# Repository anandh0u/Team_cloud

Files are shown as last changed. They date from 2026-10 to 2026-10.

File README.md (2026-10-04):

<div align="center">

# 🛏️🤖 Bedside Assistant

**A voice-controlled robotic arm and caregiver link for people who can't easily move.**









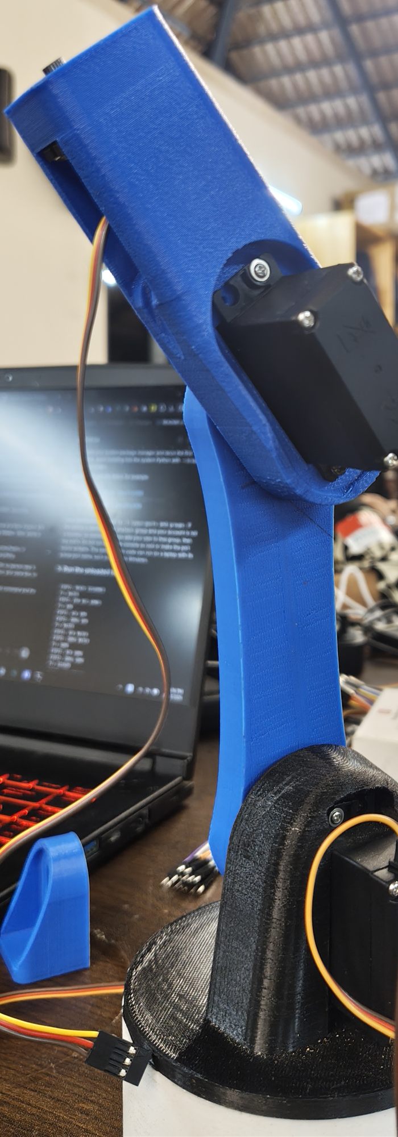
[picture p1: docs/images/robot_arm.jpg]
The 3D-printed robotic arm with MG996R servos

&nbsp;&nbsp;
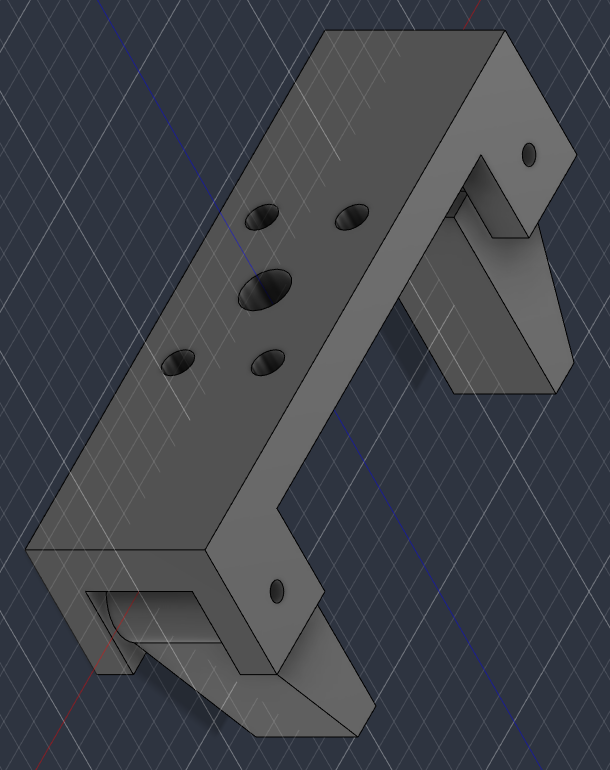
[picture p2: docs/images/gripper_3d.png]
3D model of the two-jaw gripper


</div>

---

## 💡 The problem

For someone who is bedridden, partly paralysed or in a wheelchair, everyday things are out of
reach: a glass of water, their medicine, their phone, a spoon. Asking for each one makes them
dependent on someone always being in the room, and a caregiver who steps out has no idea how
the patient is doing.

**The Bedside Assistant sits next to the bed.** The patient just speaks, in English or their own
Indian language, and a small robotic arm fetches what they need. A camera checks the object is
really there, the assistant answers out loud, and the caregiver gets a live dashboard, daily
activity reports and an immediate phone call if the patient says "help".

> ⚠️ **Hackathon prototype. Not a medical device:** it never diagnoses anything, and its pulse
> reading comes from a hobby sensor.

---

## ✨ What it does

| | |
|---|---|
| 🗣️ **Talk naturally** | "I want spoon", "can you get me something to drink", "where is my phone?" in English, Malayalam, Hindi, Tamil and other Indian languages. Replies are spoken back in the same language. |
| 🦾 **Fetch objects** | The arm opens its gripper, goes to the object's spot, grips it and holds it out to the patient. "Let go" releases it. |
| 👁️ **See the table** | A phone camera on a bedside stand runs live object detection. The arm only moves for an object the camera actually sees, and "where is my phone?" gets "on the left, next to the laptop". |
| 🚨 **Help in one word** | "Help", "I fell" or "call Ayisha" stops the arm instantly and phones the caregiver, hands-free. |
| 📊 **Caregiver dashboard** | Live camera picture, whether the patient is lying or sitting up, when they last moved, pulse, and every request and alert. Works from anywhere, behind a password. |
| 📈 **Activity reports** | Compares today with yesterday ("moved in 42% of checks, up from 30%") with a 7-day chart and a plain-language AI summary for the family. |

---

## 🧭 How it works

```mermaid
flowchart LR
    subgraph BED["🛏️ At the bedside"]
        P(["🧑‍🦽 Patient"])
        PH["📱 Bedside phone<br/>mic · camera · speaker<br/>/phone page"]
        ARM["🦾 Robotic arm<br/>base · shoulder · elbow · gripper"]
        SEN["💓 Pulse sensor<br/>📐 MPU6050"]
    end

    subgraph PI["🍓 Raspberry Pi 5: the brain"]
        INT["🧠 Intent rules<br/>+ AI fallback"]
        VIS["👁️ YOLO11<br/>objects + pose"]
        SAFE["🛡️ Safety checks"]
        DASH["📊 Dashboard · 📈 Reports<br/>🗄️ SQLite history"]
    end

    ESP["⚙️ ESP32<br/>controller"]

    subgraph CLOUD["☁️ Cloud services"]
        SAR["🗣️ Sarvam AI<br/>speech ⇄ text, translation"]
        OAI["🤖 OpenAI<br/>text + numbers only"]
    end

    subgraph CARE["👩‍⚕️ Caregiver"]
        CG["💻 Dashboard anywhere<br/>(password, HTTPS tunnel)"]
        CALL["📞 Call via MacroDroid"]
        SMS["✉️ SMS gateway phone"]
    end

    P -- speaks --> PH
    PH -- "voice + live frames" --> PI
    PI -- "spoken reply" --> PH
    PI <--> SAR
    PI <--> OAI
    PI -- "named poses only<br/>(SPOON, USER…)" --> ESP
    ESP --> ARM
    SEN --> ESP
    ESP -- telemetry --> PI
    PI --> CG
    PI --> CALL
    PI --> SMS
```

- The **phone** replaces a separate camera, microphone and speaker: it just opens a web page served by the Pi.
- The **Raspberry Pi** does all the thinking. It runs vision on its own CPU, so **camera pictures never leave the Pi**.
- The **ESP32** owns the motors. The Pi only asks for named poses (`SPOON`, `USER`, …), and the ESP32 checks them against each joint's safe limits, so no bug or bad request upstream can drive a servo into the bed.

### 🎙️ One request, end to end: *"I want my spoon"*

```mermaid
sequenceDiagram
    autonumber
    actor P as 🧑‍🦽 Patient
    participant PH as 📱 Phone
    participant PI as 🍓 Raspberry Pi
    participant S as 🗣️ Sarvam AI
    participant Y as 👁️ YOLO11 (on the Pi)
    participant E as ⚙️ ESP32 + 🦾 arm

    P->>PH: "I want my spoon"
    PH->>PI: voice clip + live camera frames
    PI->>S: speech → text (translated to English if needed)
    S-->>PI: "I want my spoon"
    Note over PI: Intent rules → GET_OBJECT spoon<br/>(AI only if no rule matches)
    PI->>Y: seen in the last 10 s?
    Y-->>PI: ✅ spoon, on the left
    PI->>E: gripper open → pose SPOON → gripper close → pose USER
    E-->>PI: ✅ done (each step waits until the arm is still)
    PI->>S: reply text → speech (patient's language)
    S-->>PI: audio
    PI-->>PH: 🔊 "I found your spoon on the left and brought it to you."
    P->>PH: "Let go"
    PI->>E: gripper open
```

### 🛡️ When does the arm actually move?

Every fetch must pass **all** of these checks. Fail any one and the arm stays still and the patient
is told why.

```mermaid
flowchart TD
    A(["🗣️ Request"]) --> B{"🚨 Emergency or STOP<br/>phrase?"}
    B -- yes --> X["🛑 Handled instantly by fixed rules<br/>(see emergency flow)"]
    B -- no --> C{"Matched by the<br/>fixed rules?"}
    C -- no --> D["🤖 AI picks a REAL action,<br/>object and contact only"]
    C -- yes --> E
    D --> E{"Can the camera<br/>recognise this object?"}
    E -- "yes (spoon, phone, cup…)" --> F{"👁️ Seen in a frame<br/>from the last 10 s?"}
    E -- "no (medicine)" --> G
    F -- no --> N1["🙅 'I can't see your spoon on the table,<br/>so I didn't move the arm.'"]
    F -- yes --> G{"📏 Pose calibrated<br/>on the ESP32?"}
    G -- no --> N2["🙅 Refused: uncalibrated pose"]
    G -- yes --> H{"⚙️ ESP32: within joint limits<br/>and not STOPPED?"}
    H -- no --> N3["🙅 Refused by the ESP32"]
    H -- yes --> M(["🦾 Arm moves"])
```

### 🚨 Emergency flow

```mermaid
flowchart LR
    H(["'Help!' / 'I fell' /<br/>'call Ayisha'"]) --> R["⚡ Matched instantly on the Pi<br/>(no internet, no AI)"]
    R --> S1["🛑 STOP the arm"]
    R --> S2["📞 Call caregiver<br/>(MacroDroid)"]
    R --> S3["✉️ SMS caregiver<br/>(if a gateway is set up)"]
    S1 & S2 & S3 --> OUT{"Did the alert<br/>get through?"}
    OUT -- yes --> Y1["🔊 'I am contacting your caregiver.'"]
    OUT -- no --> Y2["🔊 'I could not reach your caregiver.<br/>Please call out for help.'"]
```

The stop and the alert run **in parallel**, so an unreachable ESP32 can never delay the call.
After a STOP the arm refuses every motion until someone explicitly resumes it.

---

## 📁 Repository

| Folder | What |
|---|---|
| 🍓 [`raspberry_pi/`](raspberry_pi/) | The brain: Python/FastAPI server, phone page, dashboard, reports. [Setup and details →](raspberry_pi/README.md) |
| ⚙️ [`esp32_controller/`](esp32_controller/) | Arm and sensor firmware (Arduino), with a browser calibration page. [Wiring and details →](esp32_controller/README.md) |
| 🦾 [`gripper_cad/`](gripper_cad/) | 3D-printable two-jaw gripper: ready STL/STEP files and the parametric Fusion 360 script |
| 🖼️ [`docs/images/`](docs/images/) | Photos and renders used in this README |

---

## 🔧 Hardware

| Part | Notes |
|---|---|
| 🍓 Raspberry Pi 5 (4 GB+) | Runs everything on the CPU, no accelerator needed |
| ⚙️ ESP32 Dev Module | Arm and sensor controller (Wi-Fi is **2.4 GHz only**) |
| 🦾 3-joint arm + gripper, 4 hobby servos | e.g. MG996R joints, SG90 gripper; separate 5–6 V, ≥3 A supply |
| 🖨️ 3D-printed gripper | [`gripper_cad/export/`](gripper_cad/export/) |
| 📱 Android phone on a bedside stand | Camera, microphone, speaker; MacroDroid for hands-free calls |
| 💓 MPU6050, analog pulse sensor | Optional, for the dashboard |

### 🔌 Wiring

```mermaid
flowchart LR
    subgraph PWR["🔋 Servo supply 5–6 V"]
        VP["+"]
        VN["−"]
    end
    subgraph ESP["⚙️ ESP32"]
        G13["GPIO 13"]
        G14["GPIO 14"]
        G27["GPIO 27"]
        G26["GPIO 26"]
        G21["GPIO 21 SDA"]
        G22["GPIO 22 SCL"]
        G34["GPIO 34"]
        V33["3V3"]
        GND["GND"]
    end
    G13 --> BASE["Base servo"]
    G14 --> SH["Shoulder servo"]
    G27 --> EL["Elbow servo"]
    G26 --> GR["Gripper servo"]
    G21 --- MPU["📐 MPU6050"]
    G22 --- MPU
    G34 --- PUL["💓 Pulse sensor"]
    V33 --> MPU
    V33 --> PUL
    VP --> BASE & SH & EL & GR
    VN --- GND
```

| Part | ESP32 pin |
|---|---|
| Base / shoulder / elbow servo signal | **GPIO 13 / 14 / 27** |
| Gripper servo signal | **GPIO 26** |
| Servo red (+) / brown (−) | **external 5–6 V supply**, never the ESP32 |
| MPU6050 VCC / GND / SDA / SCL | **3V3** / GND / **GPIO 21** / **GPIO 22** |
| Pulse sensor + / − / S | **3V3** (not 5 V) / GND / **GPIO 34** |
| Optional STOP button | any free pin to GND (`STOP_BUTTON_PIN`) |

> 🔌 **Join all grounds:** servo supply −, every servo's brown wire, the sensor GNDs and the ESP32 GND.
> Without a common ground the servos won't move.
>
> ⚡ **Never power servos from the ESP32's VIN / 5V / 3V3.** Their current spikes reset the board and can
> stop it reading its own flash.

---

## 🚀 Quick start

1. 🍓 **Raspberry Pi:** follow [raspberry_pi/README.md](raspberry_pi/README.md#setup). With
   `MOCK_HARDWARE=true` the whole system runs with a simulated arm, so you can try it without any hardware.
2. ⚙️ **ESP32:** wire it and upload the firmware as in [esp32_controller/README.md](esp32_controller/README.md),
   then calibrate the poses in a browser at `http://<ESP32 IP>/calibrate` and put the ESP32's
   IP in the Pi's `.env`.
3. 📱 **Phone:** open `https://<Pi IP>:8443/phone`, allow camera and microphone, point it at the table.
4. 👩‍⚕️ **Caregiver:** open `http://<Pi IP>:8000/dashboard`, or `scripts/start.sh --online` for a link that works anywhere.

---

## 🎬 Demo

| Say | What happens |
|---|---|
| 👁️ "Where is my spoon?" | "I can see your spoon on the left, next to the laptop." |
| 🦾 "I want spoon" | The arm opens, goes to the spoon, grips it and holds it out: "I found your spoon on the left and brought it to you." |
| ✋ "Let go" | The gripper releases the spoon |
| 🌏 (in Malayalam) "എന്റെ ഫോൺ എവിടെ?" | Understood as "Where is my phone?" and answered in Malayalam |
| 🙅 "Bring me my phone" when it isn't on the table | "I can't see your phone on the table, so I didn't move the arm." |
| 🚨 "Help" | The arm freezes and the bedside phone calls the caregiver on speaker |
| 📈 Caregiver opens `/report` | "More active: moved in 43% of checks, compared with 30% the day before" plus an AI summary |

---

## 🛡️ Safety and privacy

- 🚨 **Emergency and STOP are matched instantly on the Pi**, with fixed replies. They never wait
  for the internet or the AI, and an emergency stops the arm and alerts the caregiver in parallel.
- 🦾 **The arm only moves for a reason:** the object must be visible in a recent camera frame, its
  pose must be calibrated, and the ESP32 enforces joint limits and refuses all motion after a STOP.
  Every step waits for the arm to be still, so a STOP is never queued behind a move.
- 🤖 **The AI is boxed in.** It only sees sentences the rules can't match, can only choose real
  actions, objects and contacts, and rewrites replies from what actually happened. If it fails,
  the fixed rules and replies take over.
- 🔒 **Privacy:** camera pictures stay on the Pi; the history stores numbers only; OpenAI receives
  text and numbers, never images. Every page sits behind a password.
- 🩺 **No diagnoses:** reports describe activity ("more active than yesterday") and never say a
  patient is improving or getting worse. Changes are flagged for the doctor or nurse.

---

## 🧰 Built with

Python · FastAPI · Ultralytics YOLO11 (detection + pose) · Sarvam AI (speech-to-text,
translation, text-to-speech for Indian languages) · OpenAI (`gpt-5.4-mini`) · SQLite ·
ESP32 / Arduino · MacroDroid · Cloudflare Tunnel · Fusion 360

✅ 248 automated tests on the Pi software, with no hardware or internet needed: `python -m pytest -q`

---

## 📌 Status and limitations

- ✅ **Working end to end on real hardware:** voice in English and Malayalam (spoken reply in
  Malayalam), live detection, camera-checked fetching with the arm, dashboard and reports.
- 📞 **Calls:** the Pi reaches MacroDroid on the bedside phone, which places the call; a full
  "help" call to the caregiver still needs a final check on the day.
- ⏱️ **Response time:** about 3–5 s in English; up to about 10 s for other languages, because
  speech recognition, the AI reply, translation and speech are each a network call. Emergency
  and STOP don't wait for the AI.
- 📍 **Fixed object spots:** the arm goes to calibrated positions, so each object has its place on
  the table. It doesn't plan a path to wherever the object is.
- 💊 **Medicine isn't recognised** by the general-purpose YOLO model. It's fetched from its spot
  without a camera check; a custom-trained model would fix that.
- 🥄 **Spoons and other small, shiny objects** are detected less reliably than bottles or phones.
  A steady camera and a plain background help.
- 📐 **Our MPU6050 is a clone** (chip ID 0x70) whose accelerometer returns zeros, so the dashboard
  shows motion as unavailable. A genuine MPU6050 works without code changes.
- ✉️ **SMS** needs an Android gateway phone; without one, messages are only logged. Calls work through MacroDroid.

---

## 🩹 Troubleshooting

| Problem | Fix |
|---|---|
| 📶 ESP32 can't find the Wi-Fi | It's 2.4 GHz only, and phone hotspots often switch to 5 GHz. Check the exact network name, including trailing spaces |
| 🦾 Servos don't move | No common ground, or no external servo power |
| 🔁 ESP32 keeps resetting / `flash read err` | Servos are powered from the ESP32. Move them to the external supply |
| ⏳ Upload stuck at `Connecting…` | Hold **BOOT** while it connects. If long uploads keep dropping, use `esp32_controller/tools/upload_chunked.ps1` |
| 🎤 Phone page has no microphone | Use the **https** address (`:8443`); browsers block the mic on plain http |
| 🔌 "The robotic arm is currently unavailable" | Check `ESP32_CONTROLLER_URL`; the ESP32's IP can change when the hotspot restarts |

---

## 🗺️ Roadmap

- 🧩 **Table zones:** YOLO picks which zone of the table an object is in, and the arm uses that zone's calibrated pose
- 💊 **Custom YOLO model** for medicine boxes and blister packs
- 📡 **Wi-Fi (OTA) firmware updates** for the ESP32, so no USB or BOOT button is needed
- 🎯 **Full positioning:** table-plane camera calibration (ArUco markers) + inverse kinematics, inside a safe boundary

---

## 🦾 Gripper

<p align="center">
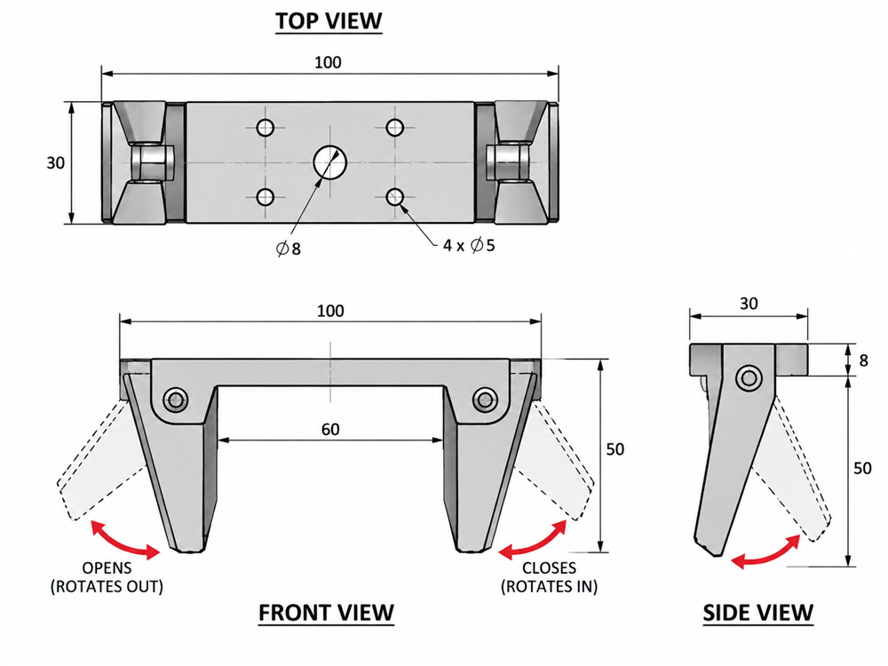
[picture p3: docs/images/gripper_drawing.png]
Gripper design drawing: 100 × 30 mm plate, two pivoting 50 mm jaws, 60 mm opening
  
</p>

Print `gripper_cad/export/Base.stl`, `Jaw_Left.stl` and `Jaw_Right.stl` in one job (PLA or PETG,
0.2 mm layers, 3–4 walls, 30–40 % infill, no supports; base plate-side down, jaws on their side).
Assemble with 2 × M3×35 bolts and nyloc nuts.

To change the dimensions, edit `gripper_cad/fusion_script/params.json`, copy the `fusion_script`
folder into Fusion 360's Scripts folder as `GripperCAD`, set `output_dir` to a folder on your
machine, and run it from **Utilities → Add-Ins**.

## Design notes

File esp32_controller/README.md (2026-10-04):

# ESP32 controller firmware

The hardware controller of the bedside assistant. It drives the 3-joint arm and the gripper,
reads the pulse sensor and the MPU6050, and takes commands from the Raspberry Pi over Wi-Fi
(HTTP + JSON).

The Pi only ever asks for **named poses** (`MEDICINE`, `USER`, …). This firmware owns the
servo angles, the joint limits and the emergency stop, so a bug or bad request on the Pi
can never drive a servo past its safe range.

Prototype only. The pulse sensor is a hobby sensor, and this firmware never classifies
medical conditions.

## Features

- **Smooth, non-blocking motion.** All joints arrive together with an eased start and stop.
  The web server never waits for a move, so `/stop` is handled immediately, even mid-move.
- **Named poses inside joint limits.** Every pose is checked against `JOINT_MIN_DEG` /
  `JOINT_MAX_DEG` at boot. Out-of-range poses are named in the Serial Monitor and refused.
- **Browser calibration** at `/calibrate`: move each joint with a slider and save the arm's
  position as a pose. Saved in flash: survives restarts, no re-upload needed.
- **Emergency stop** from the API or an optional physical button. After a stop, every motion
  command is refused until `/resume`, and resuming never moves the arm by itself.
- **Sensors:** pulse sensor with beat detection; MPU6050 movement score. The MPU6050 is read
  through its registers directly, so common clone chips work too. A sensor that isn't
  working reports `{"available": false}` instead of made-up values.
- **Wi-Fi that recovers by itself**, with diagnostics in the Serial Monitor, optional static
  IP and mDNS (`http://esp32-controller.local`).

## Hardware and wiring

ESP32 Dev Module, 4 hobby servos (e.g. MG996R for the joints, SG90 for the gripper),
MPU6050, analog pulse sensor, separate 5–6 V servo supply (at least 3 A).

| Part | ESP32 pin (default, change in `config.h`) |
|---|---|
| Base / shoulder / elbow servo signal | GPIO 13 / 14 / 27 |
| Gripper servo signal | GPIO 26 |
| MPU6050 SDA / SCL (VCC 3.3 V, GND) | GPIO 21 / 22 |
| Pulse sensor signal (+ 3.3 V, − GND) | GPIO 34 (must be 32–39: ADC2 pins stop working with Wi-Fi on) |
| Optional STOP button (other leg to GND) | set `STOP_BUTTON_PIN` |

- **Never power the servos from the ESP32's 5 V / 3.3 V pins.** The current spikes reset the ESP32.
- **Join the grounds:** the servo supply's GND must connect to the ESP32's GND.
- A 470–1000 µF capacitor across the servo supply near the servos smooths the spikes.

## Build and upload (Arduino IDE)

1. **Board package:** *File → Preferences → Additional boards manager URLs*:
   `https://espressif.github.io/arduino-esp32/package_esp32_index.json`, then in
   *Boards Manager* install **esp32 by Espressif Systems** (3.x).
2. **Board:** *Tools → Board → esp32 → ESP32 Dev Module*. *Upload Speed* 921600 (460800 if it fails).
3. **Libraries:** **ArduinoJson** 7.x and **ESP32Servo**. Nothing else is needed.
4. **Config:** copy `config.example.h` to `config.h` (git-ignored: it holds your Wi-Fi password).
   Set `WIFI_SSID`, `WIFI_PASSWORD` (2.4 GHz only), your pins, and the joint limits.
5. **Upload** `esp32_controller.ino`. If it hangs at `Connecting....`, hold **BOOT** and tap **EN**.
   If uploads fail halfway with "serial noise", use `tools/upload_chunked.ps1` (instructions inside).
6. Open the Serial Monitor at **115200** and press **EN**:

   ```
   [BOOT] esp32-controller firmware 0.3.0
   [ARM] 3 joints + gripper ready at HOME, 7 poses (6 calibrated)
   [IMU] motion sensor ready at 0x68 (chip id 0x68, MPU6050)
   [PULSE] reading pulse sensor on GPIO 34
   [WIFI] connected
   [WIFI] IP address: 192.168.1.50  RSSI: -55 dBm
   [BOOT] ready
   ```

   Put that IP in the Pi's `.env` as `ESP32_CONTROLLER_URL`.

## Calibrate the poses

Open `http://<ESP32 IP>/calibrate`:

1. Move the arm with the sliders (base, shoulder, elbow, gripper). It moves slowly and can't
   go past the joint limits. The red **STOP** button is always on screen.
2. When the arm is in place, tap **Save as …**:

   | Pose | Where the arm should be |
   |---|---|
   | `HOME` | resting, folded out of the way |
   | `SAFE` | raised, clear of everything |
   | `USER` | holding an object out to the patient's hand |
   | `MEDICINE`, `WATER`, `PHONE`, `SPOON` | gripper around each object, at its fixed spot on the table |

3. Gripper: save one angle as **OPEN** and a firm grip as **CLOSED**.
4. Check each pose with **Go**.

Pose names must match `raspberry_pi/config/poses.json`. The Pi refuses to fetch from a pose
the ESP32 reports as not calibrated. The page also prints the matching `POSE_TABLE` to paste
into `config.h`, which makes the calibration part of the code.

## HTTP API

Errors always have the form `{"ok": false, "error": "reason"}`.

| Method | Path | Reply / behaviour |
|---|---|---|
| GET | `/health` | `{"ok": true, "device", "firmware", "uptime_ms", "ip", "wifi_rssi", "free_heap"}` |
| GET | `/status` | arm (`pose`, `moving`, `angles`), `gripper`, `emergency_stop`, `poses`, `pose_angles`, `calibrated`, joint `limits` |
| GET | `/telemetry` | `heartbeat`, `imu`, `arm`, `gripper`, `emergency_stop` in one reply |
| GET | `/heartbeat` | `{"available": true, "raw": 1962, "bpm_estimate": 72.4}` or `{"available": false}` |
| GET | `/imu` | `{"available": true, "ax".."az" (m/s²), "gx".."gz" (deg/s), "movement_score"}` |
| POST | `/arm/pose` | body `{"pose": "WATER"}` → `{"ok": true, "pose": "WATER", "moving": true}`; 400 unknown pose, 409 stopped or busy |
| POST | `/arm/home` | same as a pose move to `HOME` |
| POST | `/gripper/open`, `/gripper/close` | `{"ok": true, "gripper": "OPEN", "moving": true}` |
| POST | `/stop` | freezes the arm; `{"ok": true, "emergency_stop": true}` |
| POST | `/resume` | allows motion again (doesn't move); `{"ok": true, "emergency_stop": false}` |
| GET | `/calibrate` | calibration page |
| POST | `/calibrate/jog` | `{"joint": 0, "angle": 120}` (joint 3 = gripper), within the joint limits |
| POST | `/calibrate/save` | `{"pose": "SPOON"}` or `{"gripper": "OPEN"}`: save the current position |
| POST | `/calibrate/reset` | forget all saved calibration (back to `POSE_TABLE`) |
| GET | `/debug/sensors` | pulse signal level and an I2C bus scan, with plain-language hints |
| GET | `/` | lists every endpoint |

Motion replies come back at once with `"moving": true`; the Pi polls `/status` until `moving`
is false before it sends the next step.

## Troubleshooting

| Symptom | Cause / fix |
|---|---|
| `WIFI_SSID is empty in config.h` | Fill in `config.h` and upload again |
| Dots forever, then `status 1` | Network not found: wrong name, or 5 GHz only |
| `status 4` / `status 6` | Usually a wrong password |
| The ESP32 resets when servos move | Servos powered from the ESP32, or grounds not joined |
| Servos twitch randomly | Grounds not joined |
| `MPU6050 not found` | Open `/debug/sensors`: no I2C devices = wiring/pins; a chip id other than 0x68 is a clone (works if it reads about 9.8 m/s² at rest) |
| Pulse always unavailable | `/debug/sensors` shows the raw level: 0 = not powered, flat = rest a fingertip lightly on it |
| A pose is refused at boot | The Serial Monitor names it: fix it on `/calibrate` or widen the joint limits |
| IP changes after every reboot | Set `WIFI_USE_STATIC_IP 1`, or use `http://esp32-controller.local` |

From the Pi: `python scripts/test_esp32.py` checks every read-only endpoint without moving the
arm; `python scripts/test_arm.py --pose USER --yes` moves the arm and checks that STOP blocks motion.

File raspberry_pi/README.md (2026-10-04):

# Raspberry Pi software: the assistant's brain

A FastAPI server on a Raspberry Pi 5. It listens to the patient through a phone on a bedside
stand, sees the bedside table through the same phone's camera, decides what to do, moves the
robotic arm through the ESP32, keeps the caregiver informed, and runs the caregiver's
dashboard and activity reports.

Prototype, **not a medical device**: it never diagnoses anything, and the pulse reading comes
from a hobby sensor.

## How a request flows

```
"I want spoon"  (spoken into the phone page, with live camera frames)
   │
   ├─► Sarvam speech-to-text ──► "I want spoon" (any supported Indian language → English)
   ├─► YOLO on the live frames ──► spoon seen on the left, 3 s ago
   ▼
intent rules (config/intents/en.json) ──► GET_OBJECT spoon          (AI only if no rule matches)
   ▼
router: camera saw it? pose calibrated? ──► ESP32: open → SPOON → close → USER
   ▼                                          (each step waits until the arm is still)
reply from what happened ──► AI phrasing ──► translated back ──► Sarvam speech ──► phone speaker
   ▼
dashboard event log + activity history
```

## Features

| Area | What it does |
|---|---|
| **Voice** | Sarvam speech-to-text with translation, so Malayalam, Hindi, Tamil, etc. work; replies spoken back in the patient's language |
| **Understanding** | Fixed phrase rules decide emergencies and STOP instantly; an OpenAI model handles anything the rules don't match, choosing only real actions, objects and contacts |
| **Vision** | YOLO11n on the phone's live camera (~2 frames/s, ~0.35 s each on the Pi 5 CPU): "where is my phone?", and fetches only happen if the camera saw the object |
| **Arm** | Named poses only; fixed fetch sequence (open → object → grip → hand over); "let go"; STOP at any moment; uncalibrated poses refused |
| **Emergency** | "Help", "I fell", "call Ayisha": the arm stops and the caregiver is called (and texted) at the same time |
| **Calls and texts** | Automatic calls from the bedside phone via MacroDroid; SMS via an Android gateway app; fallback to the phone's dialler |
| **Patient condition** | YOLO pose model: lying / reclined / upright, last movement, out of view; ESP32 pulse + MPU6050; "needs attention" notes |
| **Caregiver dashboard** | Live camera picture with detections, condition, sensors, every request and alert |
| **Activity report** | Day-over-day activity trend, positions, longest still period, 7-day chart, AI-written summary from the numbers only |
| **Access** | Password on every page and API call; HTTPS for the phone's microphone; optional public link via a Cloudflare tunnel |

## Setup

Raspberry Pi OS 64-bit, Python 3.11+.

```bash
cd raspberry_pi
python3 -m venv .venv && source .venv/bin/activate
pip install torch torchvision --index-url https://download.pytorch.org/whl/cpu   # small CPU build
pip install -r requirements.txt -r requirements-dev.txt
cp .env.example .env            # then fill it in: every setting is explained there
scripts/make_cert.sh            # HTTPS certificate for the phone (again if the Pi's IP changes)
python run.py                   # http://<Pi IP>:8000 and https://<Pi IP>:8443
```

With `MOCK_HARDWARE=true` (the default) everything runs without the ESP32: the arm, gripper and
sensors are simulated and every simulated value is labelled `MOCK`. The YOLO models (about 6 MB
each) download on first start.

`scripts/start.sh` restarts the server and prints the links; `scripts/start.sh --online` also
opens a Cloudflare quick tunnel with a public `https://….trycloudflare.com` address (it refuses
without `ACCESS_PASSWORD`). The address changes on every start.

### Configuration

Everything is in `.env`; [`.env.example`](.env.example) documents every setting. Required
values **fail closed**: a missing or malformed one stops startup with the variable's name,
instead of falling back to a guess. Each optional feature switches off when its first setting
is empty:

| Feature | Turned on by |
|---|---|
| Real ESP32 | `MOCK_HARDWARE=false` + `ESP32_CONTROLLER_URL` |
| Vision | `YOLO_MODEL` |
| Patient condition, activity history | `YOLO_POSE_MODEL` (+ `DATABASE_PATH` for reports) |
| Voice | `SARVAM_API_KEY` |
| AI understanding, replies, report summaries | `OPENAI_API_KEY` (+ `LLM_ASSISTANT=true`) |
| Real SMS | `COMMUNICATION_BACKEND=ANDROID_GATEWAY` |
| Automatic calls | `CALL_AUTOMATION_URL` |
| Login | `ACCESS_PASSWORD` |

Behaviour that isn't code lives in `config/`:

| File | What |
|---|---|
| `intents/en.json` | every phrase the rules understand, objects and their synonyms, contacts |
| `responses/en.json` | every fixed reply (also the facts the AI rephrases) |
| `poses.json` | the only pose names the Pi may request, and which object uses which pose |
| `vision_labels.json` | which YOLO labels count as which object (`spoon` → `spoon`, `water` → `bottle`) |
| `mock_hardware.json` | simulated sensor values (synthetic, not patient data) |

## Pages

| Page | For |
|---|---|
| `https://<Pi IP>:8443/phone` | the bedside phone: live camera with boxes, 🎤 button, typed commands, spoken replies |
| `/dashboard` | the caregiver: live picture, position, movement, pulse, alerts, every request |
| `/report` | activity trend for the last 24 h / 3 days / 7 days, with an AI summary |
| `/docs` | interactive API documentation |

The phone page needs HTTPS for the microphone. With the home-made certificate the browser warns
once: tap **Advanced → Proceed**. On plain HTTP, typing and the photo button still work.

## What the patient can say

| Say (or similar) | Result |
|---|---|
| "I want spoon", "bring me my water" | camera check, then the arm fetches it and holds it out |
| "Let go", "I have it" | gripper opens |
| "Where is my phone?" | "I can see your phone on the left, next to the laptop." |
| "Go home" | arm back to its resting pose |
| "Stop" | arm freezes; resume from the calibration page or `/arm/resume` |
| "Help", "I fell", "call Ayisha" | **emergency**: arm stops, caregiver called and alerted |
| "Call my son", "tell my daughter I'm hungry" | call / SMS to that contact |
| "How am I doing?" | arm and pulse-sensor status |

The rules are checked in a fixed order: **EMERGENCY > STOP > HOME > RELEASE > STATUS >
MESSAGE > CALL > FIND > GET**. Bare "help" is an emergency; "help me find my phone" is not.
Only sentences that match nothing go to the AI.

## Safety design

- **Emergency and STOP never wait for the network or the AI.** They are matched locally, their
  replies are fixed, and on an emergency the arm stop and the caregiver alert run in parallel,
  so an unreachable ESP32 can't delay the alert.
- **The Pi never sends angles**, only pose names from `poses.json`; the ESP32 checks them against
  its joint limits. Motion commands are sent at most once and never retried automatically.
- **Each fetch step waits until the arm is still** (the Pi polls the ESP32's `/status`), so a
  STOP during a move is never queued behind it, and a stopped step fails the whole fetch.
- **Fetches only happen when the camera saw the object** in the last 10 s, and never to a pose
  the ESP32 reports as uncalibrated. Medicine, which the standard model can't recognise, is
  fetched from its fixed spot.
- **Replies never claim what didn't happen.** The AI only rewrites the facts of the result, and
  the fixed reply is used whenever it is slow or fails.
- **No guessing:** unknown objects and contacts stay unknown; missing or implausible sensor
  readings (e.g. an accelerometer that doesn't feel gravity) are reported as unavailable.
- **Privacy:** camera pictures stay on the Pi. OpenAI receives text and numbers only; the
  history database stores numbers only. Secrets and personal numbers live in the git-ignored `.env`.
- **Not a diagnosis:** the dashboard and reports describe observations ("moved in 42% of checks,
  up from 30%"). The AI is told never to call that improving or worsening.

## Phone setup

**Bedside phone:** Chrome on the `/phone` page, on a stand facing the table. For calls with
no tap, install **MacroDroid**:

1. New macro. Trigger: *Connectivity → HTTP Server Request*, a hard-to-guess path, IP whitelist =
   the Pi's IP, variable whitelist = `number` (create a global string variable `number` first).
   Turn **Send Response** on.
2. Actions: *Phone → Make Call* → `{v=number}`; *Wait 2 s*; *Speakerphone → On*.
3. Battery usage **Unrestricted**. In `.env`: `CALL_AUTOMATION_URL=http://<phone IP>:<port>/<path>`.

**SMS (optional):** on an Android phone with a SIM, install **SMS Gateway for Android**
(sms-gate.app), start its **Local Server**, and put its address, username and password in the
`ANDROID_GATEWAY_*` settings with `COMMUNICATION_BACKEND=ANDROID_GATEWAY`.

## API

| Method | Path | What |
|---|---|---|
| POST | `/assistant/phone` | multipart `text` or `audio`, plus optional `image`: transcript, action, reply text + audio, detections, number to dial |
| POST | `/assistant/text` | `{"text": "Where is my phone?"}` |
| POST | `/vision/detect` | multipart `image`: YOLO detections (also feeds the dashboard and pose analysis) |
| POST | `/find-object` | `{"object": "phone"}` |
| GET | `/health`, `/status`, `/telemetry` | API and ESP32 health, arm state, sensor readings |
| POST | `/arm/pose`, `/arm/home`, `/arm/stop`, `/arm/resume` | direct arm control (pose names only) |
| POST | `/emergency` | stop the arm and alert the caregiver |
| POST | `/caregiver/message`, `/caregiver/call` | contact someone directly |
| GET | `/dashboard/state`, `/dashboard/frame.jpg` | dashboard data and latest camera picture |
| GET | `/report/data?hours=24&ai=true` | activity report (1–168 hours) |

The ESP32's own API is documented in [`../esp32_controller/README.md`](../esp32_controller/README.md).

## Tests

```bash
python -m pytest -q                         # 248 tests, about 5 s, no hardware or internet needed
python scripts/test_esp32.py                # read-only check of the real ESP32
python scripts/test_arm.py --pose USER --yes    # moves the real arm, checks STOP blocks motion
```

The tests use simulated hardware and fake Sarvam, OpenAI, SMS and phone services. They cover
fail-closed config, the ESP32 client (timeouts, retries, waiting for motion), intent rules,
the AI's limits, camera-checked fetching, emergencies, calls and texts, the dashboard, reports
and the login.

## Code layout

```
app/
  main.py              builds the app: services, routes, startup and shutdown
  config.py            reads and validates .env
  api/                 HTTP routes (phone, assistant, vision, dashboard, report, hardware, caregiver) + login
  assistant/           intent rules, emergency handling, router (intent → actions → reply), fixed replies
  vision/              YOLO detector, object locator ("on the left, next to the laptop")
  voice/               Sarvam speech-to-text, translation, text-to-speech
  llm/                 OpenAI: understanding + replies, report summaries
  hardware/            ESP32 client, simulator, arm service, telemetry
  patient/             pose model, condition tracker, monitor, history (SQLite), reports
  communication/       caregiver service, SMS gateway, MacroDroid dialler, mock channel
  web/                 phone, dashboard and report pages
config/                phrases, replies, poses, vision labels, simulator values
scripts/               start.sh, make_cert.sh, hardware test scripts
tests/                 pytest suite
```

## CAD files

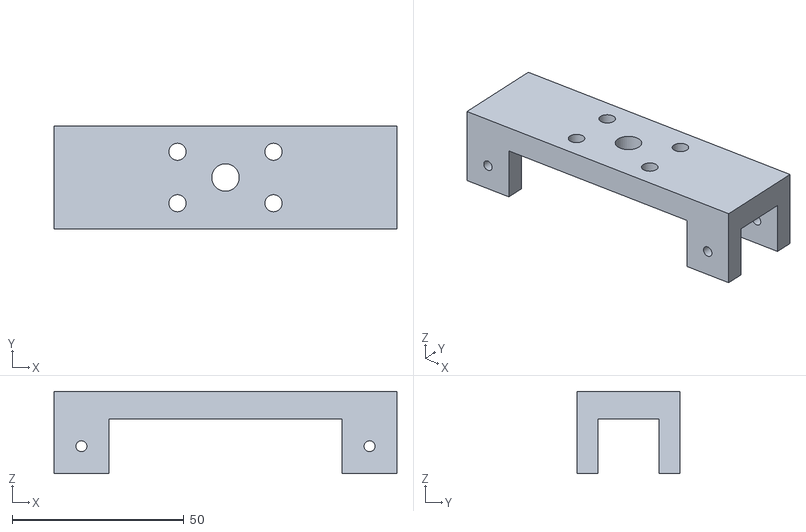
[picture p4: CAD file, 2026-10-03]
gripper_cad/export/Base.stl
100.0 x 30.0 x 24.0

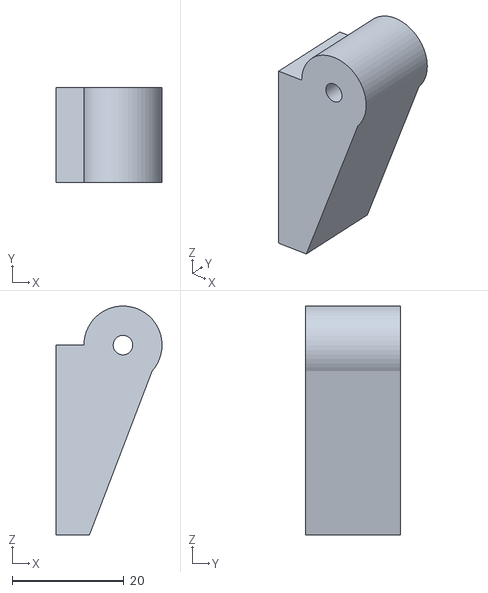
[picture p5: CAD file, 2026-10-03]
gripper_cad/export/Jaw_Right.stl
19.0 x 17.0 x 41.0

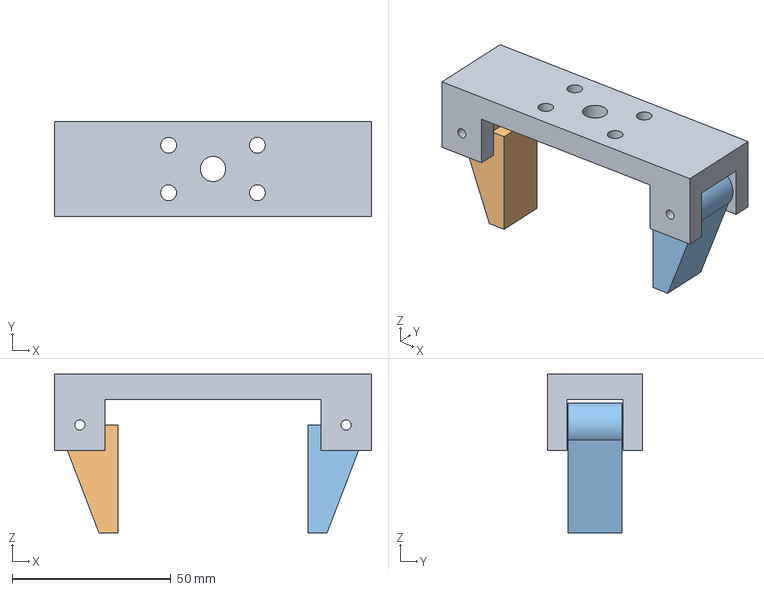
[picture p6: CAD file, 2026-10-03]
gripper_cad/export/Gripper.step
100.0 x 30.0 x 50.0 mm

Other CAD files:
gripper_cad/export/Jaw_Left.stl

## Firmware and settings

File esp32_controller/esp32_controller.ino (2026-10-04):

// ESP32 hardware controller for the assistive bedside system.
// The Raspberry Pi 5 sends commands over HTTP; this board drives the arm,
// gripper and sensors. Prototype only: no medical diagnosis.
//
// Build steps 1-11: Wi-Fi, HTTP API, arm + gripper with named poses, STOP/RESUME,
// MPU6050 and pulse sensor telemetry.

#include <ESPmDNS.h>
#include <WiFi.h>

#include "api_server.h"
#include "arm.h"
#include "config.h"
#include "sensors.h"

// Fail at compile time if config.h is missing a required setting.
#if !defined(FIRMWARE_VERSION) || !defined(DEVICE_NAME) || !defined(SERIAL_BAUD) ||       \
    !defined(WIFI_SSID) || !defined(WIFI_PASSWORD) || !defined(WIFI_CONNECT_TIMEOUT_MS) || \
    !defined(WIFI_RETRY_INTERVAL_MS) || !defined(WIFI_USE_STATIC_IP) || !defined(MDNS_ENABLED) || \
    !defined(HTTP_PORT) || !defined(JOINT_COUNT) || !defined(JOINT_PINS) || !defined(JOINT_NAMES) ||  \
    !defined(JOINT_MIN_DEG) || !defined(JOINT_MAX_DEG) || !defined(GRIPPER_PIN) ||                    \
    !defined(GRIPPER_OPEN_DEG) || !defined(GRIPPER_CLOSED_DEG) || !defined(SERVO_MIN_US) ||            \
    !defined(SERVO_MAX_US) || !defined(ARM_SPEED_DEG_S) || !defined(GRIPPER_SPEED_DEG_S) ||            \
    !defined(POSE_TABLE) || !defined(HOME_POSE) || !defined(STOP_BUTTON_PIN) || !defined(IMU_ENABLED) || \
    !defined(IMU_SDA_PIN) || !defined(IMU_SCL_PIN) || !defined(HEARTBEAT_ENABLED) ||                   \
    !defined(HEARTBEAT_PIN) || !defined(HEARTBEAT_MIN_AMPLITUDE)
#error "config.h is missing required settings. Copy config.example.h to config.h and fill it in."
#endif

static bool wifiConfigured = false;
static bool wifiWasConnected = false;
static unsigned long lastWifiRetryMs = 0;

static void onWifiConnected() {
  Serial.println("[WIFI] connected");
  Serial.printf("[WIFI] IP address: %s  RSSI: %d dBm\n",
                WiFi.localIP().toString().c_str(), WiFi.RSSI());
#if MDNS_ENABLED
  MDNS.end();
  if (MDNS.begin(DEVICE_NAME)) {
    MDNS.addService("http", "tcp", HTTP_PORT);
    Serial.printf("[WIFI] mDNS: http://%s.local\n", DEVICE_NAME);
  } else {
    Serial.println("[ERROR] mDNS failed to start (IP address still works)");
  }
#endif
}

// Logs why the access point refused or dropped us, so Wi-Fi problems are diagnosable
// from the Serial Monitor instead of guessed at.
static void onWifiEvent(WiFiEvent_t event, WiFiEventInfo_t info) {
  if (event != ARDUINO_EVENT_WIFI_STA_DISCONNECTED) return;
  const uint8_t reason = info.wifi_sta_disconnected.reason;
  const char *hint = "";
  switch (reason) {
    case WIFI_REASON_NO_AP_FOUND: hint = " (network not found: check WIFI_SSID and that it is 2.4 GHz)"; break;
    case WIFI_REASON_AUTH_FAIL:
    case WIFI_REASON_4WAY_HANDSHAKE_TIMEOUT:
    case WIFI_REASON_HANDSHAKE_TIMEOUT: hint = " (likely wrong WIFI_PASSWORD)"; break;
    case WIFI_REASON_ASSOC_FAIL:
    case WIFI_REASON_ASSOC_TOOMANY: hint = " (access point refused: device limit or block list?)"; break;
    default: break;
  }
  Serial.printf("[WIFI] disconnected, reason %u%s\n", reason, hint);
}

// Lists the networks the ESP32 can actually hear. Used when connecting fails, so
// "network not found" can be told apart from a name typo or weak reception.
static void logVisibleNetworks() {
  Serial.println("[WIFI] scanning for visible networks...");
  WiFi.disconnect();
  const int found = WiFi.scanNetworks();
  if (found <= 0) {
    Serial.printf("[WIFI] scan found no networks (result %d)\n", found);
    return;
  }
  for (int i = 0; i < found; i++) {
    Serial.printf("[WIFI]   \"%s\"  ch %d  %d dBm  auth %d%s\n", WiFi.SSID(i).c_str(), WiFi.channel(i),
                  WiFi.RSSI(i), WiFi.encryptionType(i),
                  WiFi.SSID(i) == WIFI_SSID ? "  <-- WIFI_SSID matches" : "");
  }
  WiFi.scanDelete();
}

static void startWifi() {
  wifiConfigured = strlen(WIFI_SSID) > 0;
  if (!wifiConfigured) {
    Serial.println("[ERROR] WIFI_SSID is empty in config.h. Wi-Fi disabled until it is set.");
    return;
  }

  WiFi.onEvent(onWifiEvent);
  WiFi.setHostname(DEVICE_NAME);  // must come before WiFi.mode()
  WiFi.mode(WIFI_STA);
  WiFi.setSleep(false);  // lower, steadier latency for Pi commands
  WiFi.setAutoReconnect(true);
#if WIFI_USE_STATIC_IP
  if (!WiFi.config(IPAddress(WIFI_STATIC_IP), IPAddress(WIFI_GATEWAY), IPAddress(WIFI_SUBNET))) {
    Serial.println("[ERROR] static IP configuration rejected; check WIFI_STATIC_IP/GATEWAY/SUBNET");
  }
#endif

  Serial.printf("[WIFI] connecting to \"%s\"", WIFI_SSID);
  WiFi.begin(WIFI_SSID, WIFI_PASSWORD);
  const unsigned long started = millis();
  while (WiFi.status() != WL_CONNECTED && millis() - started < WIFI_CONNECT_TIMEOUT_MS) {
    delay(250);
    Serial.print('.');
  }
  Serial.println();

  if (WiFi.status() == WL_CONNECTED) {
    wifiWasConnected = true;
    onWifiConnected();
  } else {
    Serial.printf("[ERROR] Wi-Fi not connected after %d ms (status %d). Retrying every %d ms in the background.\n",
                  WIFI_CONNECT_TIMEOUT_MS, WiFi.status(), WIFI_RETRY_INTERVAL_MS);
    logVisibleNetworks();
    WiFi.begin(WIFI_SSID, WIFI_PASSWORD);
  }
  lastWifiRetryMs = millis();
}

// Non-blocking: called every loop so a Wi-Fi drop never stalls the arm or sensors.
static void maintainWifi() {
  if (!wifiConfigured) return;

  const bool connected = WiFi.status() == WL_CONNECTED;
  if (connected && !wifiWasConnected) {
    onWifiConnected();
  } else if (!connected && wifiWasConnected) {
    Serial.println("[ERROR] Wi-Fi connection lost");
    lastWifiRetryMs = millis();
  }
  wifiWasConnected = connected;

  // WiFi.reconnect() errors out ("sta is connecting") while an attempt is still in
  // progress, so restart the attempt cleanly instead.
  if (!connected && millis() - lastWifiRetryMs >= WIFI_RETRY_INTERVAL_MS) {
    Serial.println("[WIFI] reconnecting...");
    WiFi.disconnect();
    WiFi.begin(WIFI_SSID, WIFI_PASSWORD);
    lastWifiRetryMs = millis();
  }
}

void setup() {
  Serial.begin(SERIAL_BAUD);
  delay(200);
  Serial.println();
  Serial.printf("[BOOT] %s firmware %s\n", DEVICE_NAME, FIRMWARE_VERSION);

  armBegin();  // first: servos get a defined position as early as possible
  sensorsBegin();
  startWifi();
  apiBegin();
  Serial.println("[BOOT] ready");
}

void loop() {
  armUpdate();  // smooth motion + stop button, every pass
  apiHandle();
  sensorsUpdate();
  maintainWifi();
}

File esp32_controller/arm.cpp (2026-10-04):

#include "arm.h"

#include <ESP32Servo.h>
#include <Preferences.h>

#include "config.h"

struct Pose {
  const char *name;
  float angles[JOINT_COUNT];
};

static const Pose POSES[] = POSE_TABLE;  // defaults; calibrated angles saved in flash override them
static const int POSE_COUNT = sizeof(POSES) / sizeof(POSES[0]);
static const int JOINT_PIN[JOINT_COUNT] = JOINT_PINS;
static const char *const JOINT_NAME[JOINT_COUNT] = JOINT_NAMES;
static const float JOINT_MIN[JOINT_COUNT] = JOINT_MIN_DEG;
static const float JOINT_MAX[JOINT_COUNT] = JOINT_MAX_DEG;

// Angles in use: POSE_TABLE, overridden per pose by calibration saved in flash (NVS).
static float poseAngles[POSE_COUNT][JOINT_COUNT];
static bool poseSaved[POSE_COUNT];
static float gripOpenDeg = GRIPPER_OPEN_DEG, gripClosedDeg = GRIPPER_CLOSED_DEG;
static Preferences prefs;
static const char *PREFS_NAMESPACE = "arm-cal";

static Servo joints[JOINT_COUNT];
static Servo gripper;

// Motion: every joint moves from `from` to `to` over `durationMs`, so all arrive together.
static float current[JOINT_COUNT], from[JOINT_COUNT], to[JOINT_COUNT];
static unsigned long moveStartMs = 0, moveDurationMs = 0;
static bool jointsMoving = false;

static float gripCurrent = GRIPPER_OPEN_DEG, gripFrom = GRIPPER_OPEN_DEG, gripTo = GRIPPER_OPEN_DEG;
static unsigned long gripStartMs = 0, gripDurationMs = 0;
static bool gripMoving = false;

static bool configValid = false;
static bool emergencyStop = false;
static const char *poseName = "UNKNOWN";
static const char *gripName = "OPEN";

const char *armErrorText(ArmError e) {
  switch (e) {
    case ArmError::UnknownPose: return "unknown pose";
    case ArmError::EmergencyStop: return "emergency stop active: motion refused until /resume";
    case ArmError::Busy: return "arm is still moving";
    case ArmError::ConfigInvalid: return "pose table is invalid (see Serial Monitor): motion refused";
    case ArmError::OutOfRange: return "angle outside the joint limits in config.h";
    default: return "";
  }
}

static int toMicros(float deg) {
  return SERVO_MIN_US + (int)((SERVO_MAX_US - SERVO_MIN_US) * constrain(deg, 0.0f, 180.0f) / 180.0f);
}

static int findPose(const char *name) {
  for (int i = 0; i < POSE_COUNT; i++) {
    if (strcmp(POSES[i].name, name) == 0) return i;
  }
  return -1;
}

static bool inLimits(const float *angles) {
  for (int j = 0; j < JOINT_COUNT; j++) {
    if (angles[j] < JOINT_MIN[j] || angles[j] > JOINT_MAX[j]) return false;
  }
  return true;
}

static bool validatePoses() {
  bool ok = findPose(HOME_POSE) >= 0;
  if (!ok) Serial.printf("[ERROR] HOME_POSE \"%s\" is not in POSE_TABLE\n", HOME_POSE);
  for (int i = 0; i < POSE_COUNT; i++) {
    for (int j = 0; j < JOINT_COUNT; j++) {
      if (poseAngles[i][j] < JOINT_MIN[j] || poseAngles[i][j] > JOINT_MAX[j]) {
        Serial.printf("[ERROR] pose %s: %s angle %.0f is outside %.0f-%.0f\n", POSES[i].name, JOINT_NAME[j],
                      poseAngles[i][j], JOINT_MIN[j], JOINT_MAX[j]);
        ok = false;
      }
    }
  }
  return ok;
}

// Loads POSE_TABLE, then any calibrated angles saved in flash. A saved pose that no longer
// fits the joint limits (config.h changed since) is ignored, never used.
static void loadPoses() {
  for (int i = 0; i < POSE_COUNT; i++) {
    memcpy(poseAngles[i], POSES[i].angles, sizeof(poseAngles[i]));
    poseSaved[i] = false;
    float saved[JOINT_COUNT];
    if (prefs.getBytes(POSES[i].name, saved, sizeof(saved)) == sizeof(saved)) {
      if (inLimits(saved)) {
        memcpy(poseAngles[i], saved, sizeof(saved));
        poseSaved[i] = true;
      } else {
        Serial.printf("[ARM] ignoring saved %s: outside the current joint limits\n", POSES[i].name);
      }
    }
  }
  gripOpenDeg = prefs.getFloat("grip_open", GRIPPER_OPEN_DEG);
  gripClosedDeg = prefs.getFloat("grip_closed", GRIPPER_CLOSED_DEG);
}

bool armBegin() {
  prefs.begin(PREFS_NAMESPACE, false);
  loadPoses();
  configValid = validatePoses();
  int home = findPose(HOME_POSE);
  for (int j = 0; j < JOINT_COUNT; j++) {
    current[j] = from[j] = to[j] = home >= 0 ? poseAngles[home][j] : (JOINT_MIN[j] + JOINT_MAX[j]) / 2;
    joints[j].setPeriodHertz(50);
    joints[j].attach(JOINT_PIN[j], SERVO_MIN_US, SERVO_MAX_US);
    joints[j].writeMicroseconds(toMicros(current[j]));
    delay(250);  // stagger the start-up current spikes
  }
  gripCurrent = gripFrom = gripTo = gripOpenDeg;
  gripper.setPeriodHertz(50);
  gripper.attach(GRIPPER_PIN, SERVO_MIN_US, SERVO_MAX_US);
  gripper.writeMicroseconds(toMicros(gripCurrent));
  poseName = home >= 0 ? POSES[home].name : "UNKNOWN";
#if STOP_BUTTON_PIN >= 0
  pinMode(STOP_BUTTON_PIN, INPUT_PULLUP);
#endif
  int saved = 0;
  for (int i = 0; i < POSE_COUNT; i++) saved += poseSaved[i];
  Serial.printf("[ARM] %d joints + gripper ready at %s, %d poses (%d calibrated)%s\n", JOINT_COUNT, poseName,
                POSE_COUNT, saved, configValid ? "" : " (POSE TABLE INVALID: only calibration moves allowed)");
  return configValid;
}

// Calibration moves are allowed with an invalid pose table (that's how you fix it);
// named-pose moves are not.
static ArmError checkCanMove(bool needValidConfig) {
  if (emergencyStop) return ArmError::EmergencyStop;
  if (needValidConfig && !configValid) return ArmError::ConfigInvalid;
  if (jointsMoving || gripMoving) return ArmError::Busy;
  return ArmError::None;
}

static void startJointMove(const float *target) {
  float longest = 0;
  for (int j = 0; j < JOINT_COUNT; j++) {
    from[j] = current[j];
    to[j] = constrain(target[j], JOINT_MIN[j], JOINT_MAX[j]);
    longest = max(longest, fabsf(to[j] - from[j]));
  }
  moveStartMs = millis();
  moveDurationMs = (unsigned long)(1000.0f * longest / ARM_SPEED_DEG_S);
  jointsMoving = true;
}

ArmError armMoveToPose(const char *name) {
  int i = findPose(name);
  if (i < 0) return ArmError::UnknownPose;
  ArmError err = checkCanMove(true);
  if (err != ArmError::None) return err;
  startJointMove(poseAngles[i]);
  poseName = POSES[i].name;
  Serial.printf("[ARM] moving to %s (%lu ms)\n", poseName, moveDurationMs);
  return ArmError::None;
}

ArmError armHome() { return armMoveToPose(HOME_POSE); }

static ArmError moveGripper(float target, const char *name, bool needValidConfig) {
  ArmError err = checkCanMove(needValidConfig);
  if (err != ArmError::None) return err;
  gripFrom = gripCurrent;
  gripTo = constrain(target, 0.0f, 180.0f);
  gripStartMs = millis();
  gripDurationMs = (unsigned long)(1000.0f * fabsf(gripTo - gripFrom) / GRIPPER_SPEED_DEG_S);
  gripMoving = true;
  gripName = name;
  Serial.printf("[ARM] gripper %s (%.0f deg)\n", name, gripTo);
  return ArmError::None;
}

ArmError gripperOpen() { return moveGripper(gripOpenDeg, "OPEN", true); }
ArmError gripperClose() { return moveGripper(gripClosedDeg, "CLOSED", true); }

// ------------------------------------------------------------------ calibration
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

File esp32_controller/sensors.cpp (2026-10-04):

#include "sensors.h"

#include <Wire.h>

#include "config.h"

// ------------------------------------------------------------------ MPU6050

// Talks to the registers directly instead of through a library: many boards sold as
// MPU6050 are clones (MPU6500, 6886, ...) that report a different chip ID, and strict
// libraries refuse them. The registers used here are the same on all of them.
static const uint8_t REG_CONFIG = 0x1A, REG_GYRO_CONFIG = 0x1B, REG_ACCEL_CONFIG = 0x1C,
                     REG_ACCEL_XOUT_H = 0x3B, REG_PWR_MGMT_1 = 0x6B, REG_WHO_AM_I = 0x75;
static const float ACCEL_LSB_PER_G = 8192.0f;   // +-4 g range
static const float GYRO_LSB_PER_DPS = 65.5f;    // +-500 deg/s range

static uint8_t imuAddr = 0;      // 0x68 or 0x69 once found
static uint8_t imuWhoAmI = 0;
static bool imuOk = false;
static unsigned long imuLastSampleMs = 0, imuLastRetryMs = 0;
static float ax, ay, az, gx, gy, gz;  // m/s^2 and deg/s
static float movementScore = 0;

static bool imuWrite(uint8_t reg, uint8_t value) {
  Wire.beginTransmission(imuAddr);
  Wire.write(reg);
  Wire.write(value);
  return Wire.endTransmission() == 0;
}

static bool imuRead(uint8_t reg, uint8_t *buf, size_t len) {
  Wire.beginTransmission(imuAddr);
  Wire.write(reg);
  if (Wire.endTransmission(false) != 0) return false;
  if (Wire.requestFrom(imuAddr, (uint8_t)len) != len) return false;
  for (size_t i = 0; i < len; i++) buf[i] = Wire.read();
  return true;
}

static void imuTryBegin() {
  imuLastRetryMs = millis();
  imuOk = false;
  for (uint8_t addr : {0x68, 0x69}) {  // 0x69 when the board's AD0 pin is high
    imuAddr = addr;
    uint8_t who = 0;
    if (!imuRead(REG_WHO_AM_I, &who, 1)) continue;
    imuWhoAmI = who;
    imuOk = imuWrite(REG_PWR_MGMT_1, 0x01)       // wake up, gyro clock
            && imuWrite(REG_CONFIG, 0x04)        // ~21 Hz low-pass filter
            && imuWrite(REG_GYRO_CONFIG, 0x08)   // +-500 deg/s
            && imuWrite(REG_ACCEL_CONFIG, 0x08); // +-4 g
    if (imuOk) {
      Serial.printf("[IMU] motion sensor ready at 0x%02X (chip id 0x%02X%s)\n", addr, who,
                    who == 0x68 ? ", MPU6050" : ", compatible clone");
      return;
    }
  }
  Serial.println("[ERROR] MPU6050 not found at 0x68/0x69 (check SDA/SCL, 3.3 V, GND); retrying every 5 s");
}

static void imuUpdate() {
#if IMU_ENABLED
  if (!imuOk) {
    if (millis() - imuLastRetryMs > 5000) imuTryBegin();
    return;
  }
  if (millis() - imuLastSampleMs < 20) return;  // 50 Hz
  imuLastSampleMs = millis();
  uint8_t b[14];  // accel x/y/z, temperature, gyro x/y/z: big-endian 16-bit each
  if (!imuRead(REG_ACCEL_XOUT_H, b, sizeof(b))) {
    imuOk = false;
    Serial.println("[ERROR] MPU6050 read failed; retrying");
    return;
  }
  auto word = [&](int i) { return (int16_t)((b[i] << 8) | b[i + 1]); };
  const float G = 9.80665f;
  ax = word(0) / ACCEL_LSB_PER_G * G; ay = word(2) / ACCEL_LSB_PER_G * G; az = word(4) / ACCEL_LSB_PER_G * G;
  gx = word(8) / GYRO_LSB_PER_DPS; gy = word(10) / GYRO_LSB_PER_DPS; gz = word(12) / GYRO_LSB_PER_DPS;
  // Movement score: how far the total acceleration is from still (1 g) plus how fast it
  // rotates, smoothed over about 2 s. 0 = still; roughly 1+ = clear movement. Unitless.
  float accelDev = fabsf(sqrtf(ax * ax + ay * ay + az * az) - 9.81f);
  float rotation = sqrtf(gx * gx + gy * gy + gz * gz) / 50.0f;
  movementScore += 0.01f * ((accelDev + rotation) - movementScore);
#endif
}

void imuToJson(JsonObject out) {
  out["available"] = (bool)(IMU_ENABLED && imuOk);
  if (!(IMU_ENABLED && imuOk)) return;
  out["ax"] = roundf(ax * 1000) / 1000; out["ay"] = roundf(ay * 1000) / 1000; out["az"] = roundf(az * 1000) / 1000;
  out["gx"] = roundf(gx * 100) / 100; out["gy"] = roundf(gy * 100) / 100; out["gz"] = roundf(gz * 100) / 100;
  out["movement_score"] = roundf(movementScore * 1000) / 1000;
}

// ------------------------------------------------------------------ pulse sensor

static const int IBI_COUNT = 5;
static int hbRaw = 0;
static float hbBaseline = 0, hbMax = 0, hbMin = 4095;
static bool hbAbove = false;
static unsigned long hbLastSampleMs = 0, hbLastBeatMs = 0;
static unsigned long ibis[IBI_COUNT];
static int ibiCount = 0, ibiNext = 0;

static void heartbeatUpdate() {
#if HEARTBEAT_ENABLED
  if (millis() - hbLastSampleMs < 10) return;  // 100 Hz
  hbLastSampleMs = millis();
  hbRaw = analogRead(HEARTBEAT_PIN);
  if (hbBaseline == 0) hbBaseline = hbRaw;
  hbBaseline += 0.02f * (hbRaw - hbBaseline);
  // Envelope that slowly decays back towards the baseline, so the threshold follows the signal.
  hbMax = max(hbMax - 0.5f, (float)hbRaw);
  hbMin = min(hbMin + 0.5f, (float)hbRaw);
  float amplitude = hbMax - hbMin;
  if (amplitude < HEARTBEAT_MIN_AMPLITUDE) {
    hbAbove = false;  // flat or noisy: no finger on the sensor
    return;
  }
  float threshold = hbBaseline + amplitude * 0.25f;
  if (!hbAbove && hbRaw > threshold) {
    hbAbove = true;
    unsigned long now = millis();
    unsigned long ibi = now - hbLastBeatMs;
    if (hbLastBeatMs != 0 && ibi >= 300 && ibi <= 2000) {  // 30-200 bpm
      ibis[ibiNext] = ibi;
      ibiNext = (ibiNext + 1) % IBI_COUNT;
      if (ibiCount < IBI_COUNT) ibiCount++;
    }
    if (hbLastBeatMs == 0 || ibi >= 300) hbLastBeatMs = now;
  } else if (hbAbove && hbRaw < hbBaseline) {
    hbAbove = false;
  }
#endif
}

void heartbeatToJson(JsonObject out) {
  // Only report a pulse while beats keep coming; a stale number is worse than none.
  bool recent = hbLastBeatMs != 0 && millis() - hbLastBeatMs < 3000;
  bool available = HEARTBEAT_ENABLED && recent && ibiCount >= 3;
  out["available"] = available;
  if (!available) return;
  unsigned long sum = 0;
  for (int i = 0; i < ibiCount; i++) sum += ibis[i];
  out["raw"] = hbRaw;
  out["bpm_estimate"] = roundf(600000.0f * ibiCount / sum) / 10;
}

// ------------------------------------------------------------------ diagnostics
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

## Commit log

2026-10-03 Add Raspberry Pi backend, ESP32 controller firmware and gripper CAD
    - raspberry_pi: config (fail-closed env + JSON catalogs), logging, GET /health,
    ESP32 HTTP client (timeouts, safe retries, ok=false handling), mock hardware,
    named-pose arm service, telemetry parsing; 35 passing tests
    - esp32_controller: Arduino sketch with Wi-Fi (reconnect, static IP, mDNS),
    GET / and GET /health; later endpoints return 501 ok=false
    - gripper_cad: Fusion 360 script + params and exported STL/STEP parts
    [Base.stl, Gripper.step, Jaw_Left.stl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]
2026-10-03 esp32_controller: Wi-Fi diagnostics, reconnect fix, chunked upload script
    - Log the Wi-Fi disconnect reason with hints (wrong password, network not
    found, AP refused) and list visible networks when the first connect fails
    - Restart the connection with disconnect()+begin() instead of reconnect(),
    which errored with "sta is connecting" and interrupted slow attempts
    - tools/upload_chunked.ps1: flash the app in 64 KB verified chunks with
    per-chunk retry, for boards whose long uploads drop mid-transfer
    Verified on hardware: ESP32-D0WD-V3 joins the hotspot, GET /health and
    GET / respond, unimplemented endpoints return 501 {"ok": false}.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
    [esp32_controller.ino]
2026-10-03 raspberry_pi: assistant text API, intent parser, emergency handling
    - Deterministic intent parser driven by config/intents/en.json
    (EMERGENCY > STOP > HOME > STATUS > MESSAGE > CALL > FIND > GET > UNKNOWN);
    bare "help" only counts as the whole sentence, "I need help" anywhere,
    calling the caregiver escalates to EMERGENCY
    - Emergency handler stops the arm and alerts the caregiver concurrently and
    only claims success if the alert was delivered
    - Router: GET_OBJECT runs a fixed named-pose sequence and stops at the first
    failed step; FIND_OBJECT never reports a location without a camera result
    - Caregiver communication abstraction with a MOCK (log-only) backend
    - Routes: /status, /tele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
2026-10-04 Bedside assistant: voice, live vision, dashboard, reports, calls; ESP32 arm + sensors
    Raspberry Pi:
    - Phone page (/phone): Sarvam speech-to-text/text-to-speech, replies in the
    patient's language, live YOLO detection boxes, "where is my X" from the camera
    - Caregiver dashboard (/dashboard): pose-based position/movement, ESP32 sensors,
    live camera frame, event log; activity history (SQLite) and /report with a
    7-day chart and an OpenAI summary built from numbers only
    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
2026-10-04 esp32: read MPU6050 registers directly (clone chips work), add /debug/sensors
    The Adafruit driver rejects boards whose chip ID isn't exactly 0x68, which many
    MPU6050 clones report differently. /debug/sensors shows the pulse signal level and
    an I2C bus scan to diagnose wiring.
2026-10-04 esp32: browser calibration page, poses saved in flash
    /calibrate moves each joint with a slider (inside the joint limits, STOP always
    on screen) and saves the arm's position as a named pose or gripper angle in NVS,
    overriding POSE_TABLE without re-uploading. /status now reports pose angles,
    which are calibrated, and the joint limits.
2026-10-04 pi: drop implausible IMU readings (no gravity = sensor not really measuring)
    MPU6050 clones reporting chip id 0x70 can return an all-zero accelerometer,
    which would otherwise show on the dashboard as constant motion.
2026-10-04 pi: camera-checked fetching, 'let go' command, never use uncalibrated poses
    'I want spoon' now fetches only if the camera sees a spoon in a recent photo
    (and says where); not seen or no photo = the arm doesn't move. Objects the model
    can't recognise (medicine) are fetched unverified from their fixed spot. A pose the
    ESP32 reports as uncalibrated is refused. New RELEASE intent ('let go', 'I have it')
    opens the gripper after a hand-over.
2026-10-04 pi: objects count as seen if any live frame in the last 10 s showed them
    A handheld phone catches a small object like a spoon in some frames and misses it
    in others, so checking only the latest frame made fetches fail at random.
2026-10-04 Docs and cleanup for submission
    - README: rewritten as the project overview (problem, features, architecture,
    hardware, quick start, demo, safety and privacy, honest status and limitations)
    - raspberry_pi/README: reorganised around setup, pages, commands, safety design,
    phone setup, API, tests and code layout; drops the build-phase history
    - esp32_controller/README: reference docs (features, wiring, build, calibration,
    API, troubleshooting) instead of a build diary
    - .env.example regrouped by feature with every setting explained; removed the
    unused ESP32 camera, Anthropic and WEBHOOK options
    - requirements.txt lists only what the code uses (dropped sounddevice, pandas,
    scikit-learn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
2026-10-04 README: diagrams, images and emoji polish
    Keeps all of the submission README's content and adds:
    - Mermaid diagrams: system architecture, end-to-end request sequence,
    arm safety gates, emergency flow, wiring
    - Images: arm photo (cropped so no bystanders are visible), gripper 3D
    render and design drawing in docs/images/
    - Badges and emoji section headers
    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
